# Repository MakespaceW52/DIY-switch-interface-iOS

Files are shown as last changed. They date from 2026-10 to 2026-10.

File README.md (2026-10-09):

# DIY BLE Switch Interface Module

> **A DIY Bluetooth accessibility switch interface for people with motor impairments — inspired by commercial devices like the AbleNet Blue2.**
---

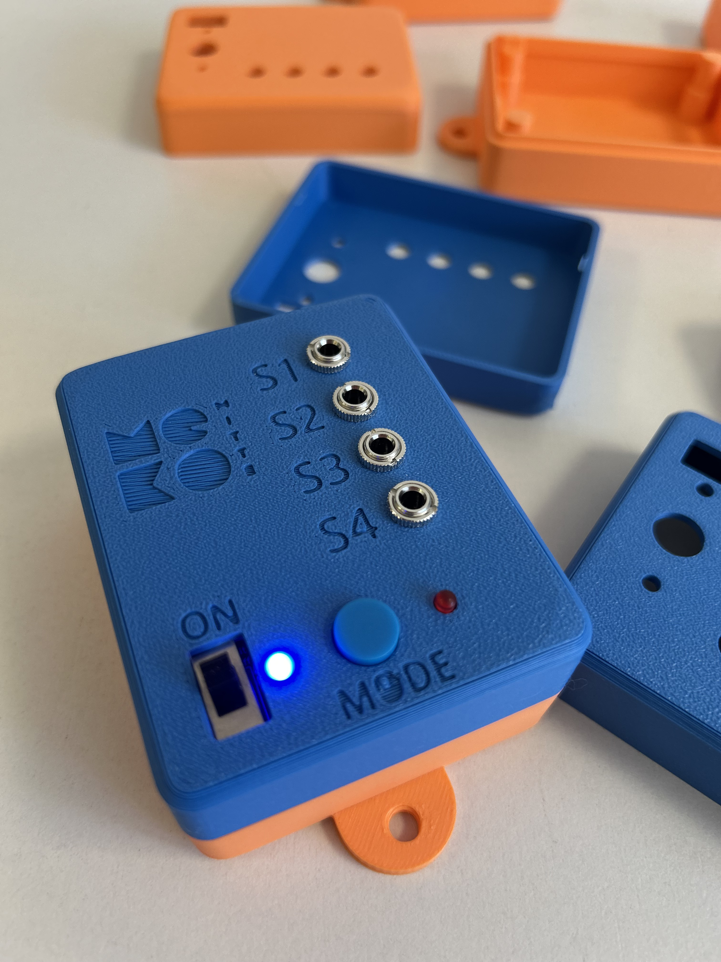
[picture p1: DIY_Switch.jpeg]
Ein Schalter Interface mit Klinkenbuchsen in einem selbstgedruckten Gehäuse.
\
Photo: © Meko Mitte

Bei Fragen / for questions contact: makespace@tjfbg.de

## English

### What is this?

The DIY BLE Switch Interface Module is an open-source Bluetooth HID adapter that connects up to **4 external switches** (via 3.5mm mono jack sockets) to iOS devices via Bluetooth Low Energy. A mode button cycles through configurable action profiles. Two LEDs indicate the current mode and Bluetooth connection status.

This project was developed at **Meko Mitte**, in their public makerspace for children and young people in Berlin, as an affordable and adaptable alternative to commercial assistive technology devices.

### Use Cases

- **Switch Control (iOS)** — Navigate the operating system's built-in accessibility features using one or more external switches (e.g. sip-and-puff, head switch, hand switch)
- **Media Control** — Play/pause, next/previous track, home button — for people who cannot easily reach device controls
- **Custom Input** — Any key combination or consumer HID command, freely configurable per switch and per mode
- **AAC Support** — Can be used as a switch interface for augmentative and alternative communication (AAC) apps

### Components

| Component | Description |
|---|---|
| **Adafruit Feather nRF52832 Bluefruit LE** | Main microcontroller board with integrated BLE (nRF52832 chip). Runs the Arduino sketch and handles all Bluetooth HID communication. |
| **3.5mm Mono Jack Sockets (×4)** | Input connectors for external switches. Tip → GPIO pin, Sleeve → GND. Compatible with most standard assistive technology switches. |
| **Push Button (momentary, NO)** | Mode selection button. Cycles through the configured action profiles. Each mode change is confirmed by the red LED blinking. |
| **LED red (3mm diffuse)** | Mode indicator. Blinks X times to confirm the active mode (1× = Mode 0, 2× = Mode 1, 3× = Mode 2). |
| **LED blue (3mm diffuse)** | Bluetooth status indicator. Slow blink = searching for device. Steady on = connected. Brief off = command sent. |
| **Resistor 330Ω** | Current limiting resistor for the red LED. |
| **Resistor 100Ω** | Current limiting resistor for the blue LED (higher forward voltage). |
| **Toggle Switch SPDT (2MS1)** | Power switch. Connected to the EN pin of the Feather to disable the 3.3V regulator when off. Protects the LiPo battery from deep discharge. |
| **LiPo Battery** | Powers the module wirelessly. The Feather's onboard charging circuit charges the battery via USB. |
| **Custom PCB** | KiCad-designed carrier board for all components. Gerber files included. |
| **3D Printed Enclosure** | Printable housing (FDM, PETG recommended). Source files and STLs included. |

### Modes (configurable in code)

| Mode | S1 | S2 | S3 | S4 |
|---|---|---|---|---|
| 0 – Switch Control | Space | Enter | Tab | Escape |
| 1 – Media | Play/Pause | Next | Previous | Home |
| 2 – Custom | 'a' | 'b' | disabled | disabled |

### Pin Assignment

| Function | Pin | Note |
|---|---|---|
| Switch 1 | 7 | INPUT_PULLUP |
| Switch 2 | 11 | INPUT_PULLUP |
| Switch 3 | 15 | INPUT_PULLUP |
| Switch 4 | 16 | INPUT_PULLUP |
| Mode Button | A5 (P0.29) | INPUT_PULLUP |
| LED red | A0 (P0.26) | via 330Ω |
| LED blue | A1 (P0.27) | via 100Ω |
| Power Switch | EN pin | SPDT to GND |

### Build Your Own

1. **Order the PCB** — Upload the Gerber files from `/pcb/` to a PCB manufacturer (e.g. JLCPCB, PCBWay, Aisler)
2. **Print the enclosure** — Print the files from `/case/` in PLA. Layer height 0.2mm, 3–4 wall lines.
3. **Solder the components** — Follow the schematic in kicad files in `/pcb/`
4. **Flash the firmware** — Open `_DIY_iOS_Blueetooth_Switch_v5.ino` in Arduino IDE, select board `Adafruit Bluefruit nRF52832 Feather`, upload
5. **Pair via Bluetooth** — The device appears as `DIY_Switch`. Enable Switch Control or accessibility features on your device and connect.

> **Note on power:** The EN-pin switch cuts the 3.3V regulator. The LiPo charging circuit remains active. Always use a protected LiPo battery.

### License

Open source — built with ❤️ at Meko Mitte for and with the community.

---

## Deutsch

### Was ist das?

Das DIY BLE Switch Interface Module ist ein Open-Source Bluetooth-HID-Adapter, der bis zu **4 externe Schalter** (über 3,5mm Mono-Klinkenbuchsen) per Bluetooth Low Energy mit iOS verbindet. Ein Modus-Button schaltet zwischen konfigurierbaren Aktionsprofilen um. Zwei LEDs zeigen den aktiven Modus und den Bluetooth-Verbindungsstatus an.

Das Projekt entstand im **Meko Mitte**, in deren öffentlichem Makespace für Kinder und Jugendliche in Berlin, als erschwingliche und anpassbare Alternative zu kommerziellen Hilfsmittelgeräten.

### Anwendungsszenarien

- **Switch Control (iOS)** — Steuerung der eingebauten Bedienungshilfen des Betriebssystems mit einem oder mehreren externen Schaltern (z.B. Sip-and-Puff, Kopfschalter, Handschalter)
- **Mediensteuerung** — Play/Pause, Nächster/Vorheriger Titel, Home-Taste — für Menschen, die Gerätebedienelemente schwer erreichen können
- **Benutzerdefinierte Eingabe** — Beliebige Tastenkombinationen oder Consumer-HID-Befehle, frei konfigurierbar pro Schalter und pro Modus
- **UK / Unterstützte Kommunikation** — Einsatz als Schalterinterface für UK-Apps (Unterstützte und Alternative Kommunikation)

### Komponenten

| Komponente | Beschreibung |
|---|---|
| **Adafruit Feather nRF52832 Bluefruit LE** | Haupt-Mikrocontroller-Board mit integriertem BLE (nRF52832-Chip). Führt den Arduino-Sketch aus und übernimmt die gesamte Bluetooth-HID-Kommunikation. |
| **3,5mm Mono-Klinkenbuchsen (×4)** | Eingänge für externe Schalter. Tip → GPIO-Pin, Sleeve → GND. Kompatibel mit den meisten Standard-Hilfsmittelschaltern. |
| **Drucktaster (momentan, NO)** | Modus-Wahltaster. Schaltet durch die konfigurierten Aktionsprofile. Jeder Moduswechsel wird durch Blinken der roten LED bestätigt. |
| **LED rot (3mm diffus)** | Modus-Anzeige. Blinkt X-mal zur Bestätigung des aktiven Modus (1× = Modus 0, 2× = Modus 1, 3× = Modus 2). |
| **LED blau (3mm diffus)** | Bluetooth-Statusanzeige. Langsames Blinken = Suche nach Gerät. Dauerhaft an = verbunden. Kurz aus = Befehl gesendet. |
| **Widerstand 330Ω** | Vorwiderstand für die rote LED. |
| **Widerstand 100Ω** | Vorwiderstand für die blaue LED (höhere Flussspannung). |
| **Kippschalter SPDT (2MS1)** | Ein-/Ausschalter. Am EN-Pin des Feather angeschlossen, um den 3,3V-Regler abzuschalten. Schützt den LiPo-Akku vor Tiefentladung. |
| **LiPo-Akku** | Versorgt das Modul kabellos mit Strom. Der integrierte Ladekreis des Feather lädt den Akku per USB. |
| **Eigene Platine (PCB)** | In KiCad entworfene Trägerplatine für alle Komponenten. Gerber-Dateien inklusive. |
| **3D-gedrucktes Gehäuse** | Druckbares Gehäuse (FDM, PETG empfohlen). Quelldateien und STLs inklusive. |

### Modi (im Code konfigurierbar)

| Modus | S1 | S2 | S3 | S4 |
|---|---|---|---|---|
| 0 – Switch Control | Leertaste | Enter | Tab | Escape |
| 1 – Medien | Play/Pause | Weiter | Zurück | Home |
| 2 – Benutzerdefiniert | 'a' | 'b' | deaktiviert | deaktiviert |

### Pinbelegung

| Funktion | Pin | Hinweis |
|---|---|---|
| Schalter 1 | 7 | INPUT_PULLUP |
| Schalter 2 | 11 | INPUT_PULLUP |
| Schalter 3 | 15 | INPUT_PULLUP |
| Schalter 4 | 16 | INPUT_PULLUP |
| Modus-Button | A5 (P0.29) | INPUT_PULLUP |
| LED rot | A0 (P0.26) | über 330Ω |
| LED blau | A1 (P0.27) | über 100Ω |
| Ein-/Ausschalter | EN-Pin | SPDT nach GND |

### Selbstbau

1. **Platine bestellen** — Gerber-Dateien aus `/pcb/` bei einem PCB-Hersteller hochladen (z.B. JLCPCB, PCBWay, Aisler)
2. **Gehäuse drucken** — Dateien aus `/case/` in PLA drucken.
3. **Komponenten löten** — Schaltplan in kicad datei `/pcb/` als Vorlage nutzen
4. **Firmware flashen** — `_DIY_iOS_Blueetooth_Switch_v5.ino` in der Arduino IDE öffnen, Board `Adafruit Bluefruit nRF52832 Feather` auswählen, hochladen
5. **Bluetooth koppeln** — Das Gerät erscheint als `DIY_Switch`. Switch Control oder Bedienungshilfen am Zielgerät aktivieren und verbinden.

> **Hinweis zum Akku:** Der EN-Pin-Schalter trennt den 3,3V-Regler. Der LiPo-Ladekreis bleibt aktiv. Bitte immer geschützte LiPo-Akkus verwenden.

### Lizenz

Open Source — mit ❤️ bei Meko Mitte für und mit der Community entstanden.

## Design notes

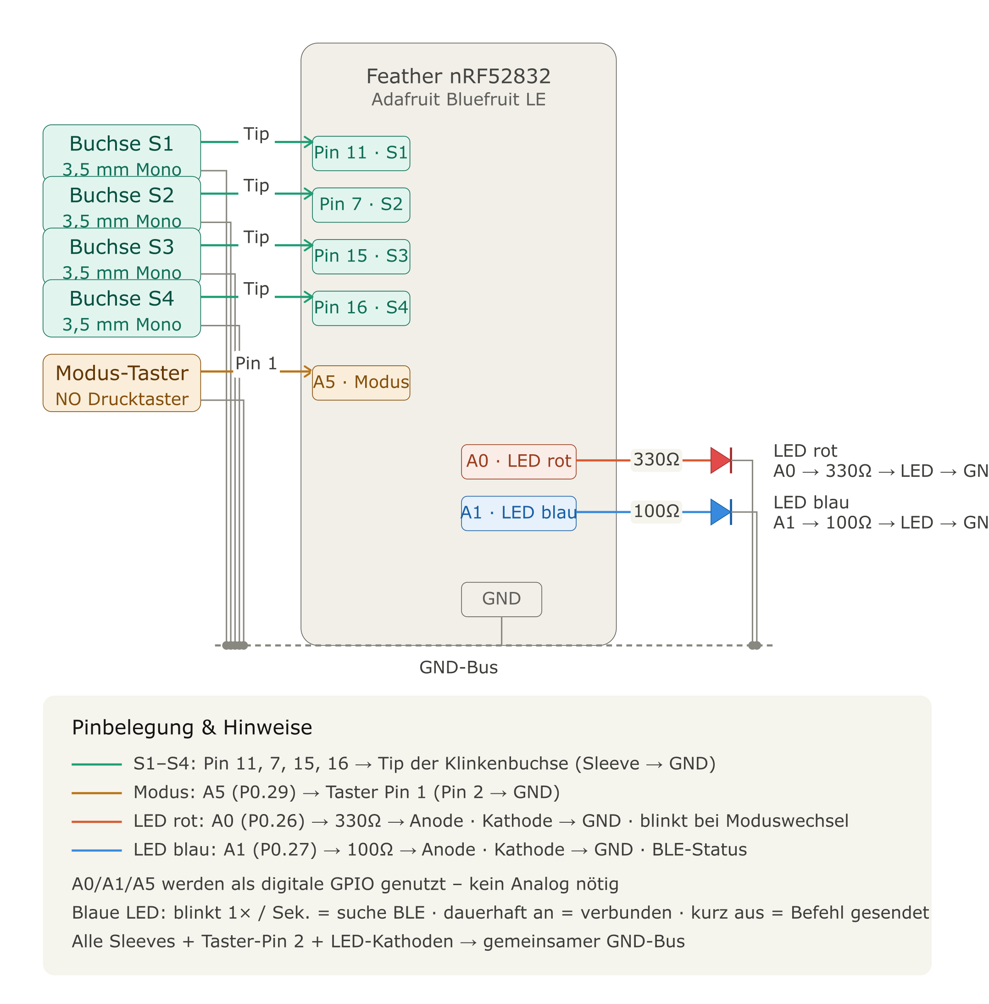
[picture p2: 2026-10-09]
schaltplan_v5.png

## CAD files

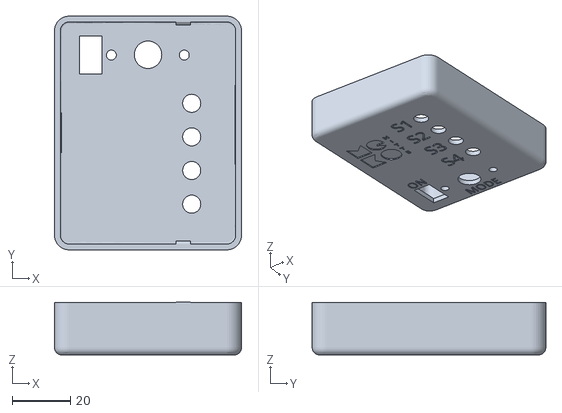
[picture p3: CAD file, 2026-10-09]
case/DIY-Switch_top_v5.stl
64.0 x 80.0 x 18.1

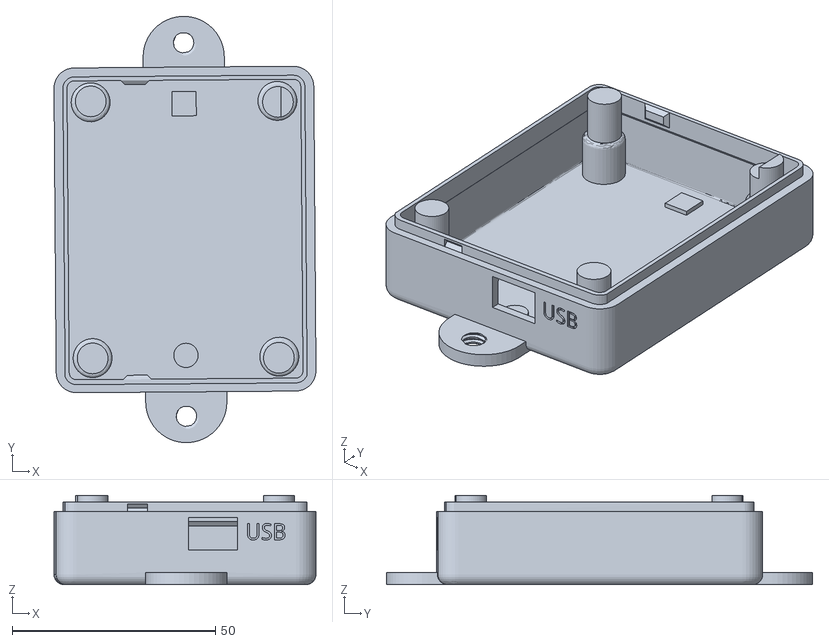
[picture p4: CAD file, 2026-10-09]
case/DIY-Switch_bottom_v4.stl
64.5 x 105.0 x 22.0

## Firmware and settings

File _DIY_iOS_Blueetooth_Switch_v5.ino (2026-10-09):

/*********************************************************************
 * DIY BLE Switch Module – nRF52 (Adafruit Feather 52 / Bluefruit)
 *
 * 4 externe Schalter (Mono-Klinkenbuchsen, INPUT_PULLUP)
 * 1 Modus-Button zum Durchschalten der Modi
 * LED rot  – blinkt X-mal bei Moduswechsel
 * LED blau – zeigt BLE-Verbindungsstatus
 *
 * ---------------------------------------------------------------
 * KONFIGURATION: Nur diesen Abschnitt anpassen
 * ---------------------------------------------------------------
 *********************************************************************/
#include <bluefruit.h>

// --- Pin-Definitionen -------------------------------------------
const int PIN_S1        = 7;   // Schalter 1 (Klinkenbuchse)
const int PIN_S2        = 11;   // Schalter 2 (Klinkenbuchse)
const int PIN_S3        = 15;   // Schalter 3 (Klinkenbuchse)
const int PIN_S4        = 16;   // Schalter 4 (Klinkenbuchse)
const int PIN_MODE_BTN  = PIN_A5;   // Modus-Wechsel-Button  (A5 = P0.29)
const int PIN_LED_RED   = PIN_A0;   // Externe rote LED  – Modus-Anzeige (A0 = P0.26)
const int PIN_LED_BLUE  = PIN_A1;   // Externe blaue LED – BLE-Status    (A1 = P0.27)

// --- BLE-Gerätename ---------------------------------------------
const char* DEVICE_NAME = "DIY_Switch";

// --- Anzahl Modi ------------------------------------------------
const int NUM_MODES = 3;

// --- Aktionstypen -----------------------------------------------
#define TYPE_NONE     0   // Schalter deaktiviert
#define TYPE_KEY      1   // Tastatur-Zeichen (HID keyPress)
#define TYPE_CONSUMER 2   // Consumer-Control (z.B. Play/Pause)

// --- HID Consumer-Codes -----------------------------------------
#define CONTROL_PLAY_PAUSE      0x00CD
#define CONTROL_SCAN_NEXT       0x00B5
#define CONTROL_SCAN_PREVIOUS   0x00B6
#define CONTROL_MUTE            0x00E2
#define AC_FORWARD              0x0225
#define AC_BACK                 0x0224
#define CONSUMER_BROWSER_HOME   0x0223

// --- Modus-Tabelle ----------------------------------------------
// Aufbau pro Eintrag: { TYPE, Wert }
// TYPE_KEY      -> Wert = ASCII-Zeichen (z.B. ' ', '\n', '\t', 27=Esc)
// TYPE_CONSUMER -> Wert = HID Consumer-Code (z.B. CONTROL_PLAY_PAUSE)
// TYPE_NONE     -> Wert wird ignoriert

struct Action {
  uint8_t  type;
  uint16_t value;
};

// [Modus][Schalter S1..S4]
const Action modeConfig[NUM_MODES][4] = {
  // Modus 0: Switch Control (Bedienungshilfen iOS/Android)
  {
    { TYPE_KEY,      ' '   },   // S1 – Leertaste  (Select / Aktivieren)
    { TYPE_KEY,      '\n'  },   // S2 – Enter
    { TYPE_KEY,      '\t'  },   // S3 – Tab        (Vorwärts navigieren)
    { TYPE_KEY,      27    },   // S4 – Escape     (Zurück / Abbrechen)
  },
  // Modus 1: Mediensteuerung
  {
    { TYPE_CONSUMER, CONTROL_PLAY_PAUSE    },   // S1 – Play/Pause
    { TYPE_CONSUMER, CONTROL_SCAN_NEXT     },   // S2 – Nächster Titel
    { TYPE_CONSUMER, CONTROL_SCAN_PREVIOUS },   // S3 – Vorheriger Titel
    { TYPE_CONSUMER, CONSUMER_BROWSER_HOME },   // S4 – Home
  },
  // Modus 2: Benutzerdefiniert – hier frei belegen
  {
    { TYPE_KEY,      'a'   },   // S1
    { TYPE_KEY,      'b'   },   // S2
    { TYPE_NONE,     0     },   // S3 – deaktiviert
    { TYPE_NONE,     0     },   // S4 – deaktiviert
  },
};

// ---------------------------------------------------------------
// Ab hier: Laufzeit-Logik – normalerweise nicht anfassen
// ---------------------------------------------------------------

BLEDis          bledis;
BLEHidAdafruit  blehid;

// Pin-Array für die 4 Schalter
const int switchPins[4] = { PIN_S1, PIN_S2, PIN_S3, PIN_S4 };

// Debounce-Status
bool prevSwitchState[4] = { HIGH, HIGH, HIGH, HIGH };
bool prevModeBtnState   = HIGH;

// Aktiver Modus
int currentMode = 0;

// BLE-Verbindungsstatus
bool bleConnected = false;

// Timing für blaues BLE-Blinken (non-blocking)
unsigned long lastBlueToggle = 0;
bool          blueState      = false;

// ---------------------------------------------------------------
// BLE Callbacks
// ---------------------------------------------------------------
void connectCallback(uint16_t conn_hdl) {
  (void) conn_hdl;
  bleConnected = true;
  digitalWrite(PIN_LED_BLUE, HIGH);   // Dauerhaft an = verbunden
  Serial.println("BLE verbunden");
}

void disconnectCallback(uint16_t conn_hdl, uint8_t reason) {
  (void) conn_hdl;
  (void) reason;
  bleConnected = false;
  digitalWrite(PIN_LED_BLUE, LOW);
  Serial.println("BLE getrennt");
}

// ---------------------------------------------------------------
// Setup
// ---------------------------------------------------------------
void setup() {
  for (int i = 0; i < 4; i++) {
    pinMode(switchPins[i], INPUT_PULLUP);
  }
  pinMode(PIN_MODE_BTN,  INPUT_PULLUP);
  pinMode(PIN_LED_RED,   OUTPUT);
  pinMode(PIN_LED_BLUE,  OUTPUT);
  digitalWrite(PIN_LED_RED,  LOW);
  digitalWrite(PIN_LED_BLUE, LOW);

  Serial.begin(115200);
  unsigned long t = millis();
  while (!Serial && millis() - t < 2000) delay(10);

  Serial.println("DIY BLE Switch Module – Start");
  Serial.print("Modi: ");
  Serial.println(NUM_MODES);

  Bluefruit.begin();
  Bluefruit.setTxPower(4);
  Bluefruit.setName(DEVICE_NAME);

  // BLE Callbacks registrieren
  Bluefruit.Periph.setConnectCallback(connectCallback);
  Bluefruit.Periph.setDisconnectCallback(disconnectCallback);

  bledis.setManufacturer("Meko Mitte");
  bledis.setModel("BLE Switch v2");
  bledis.begin();

  blehid.begin();

  startAdv();

  // Startmodus anzeigen (rote LED)
  blinkMode(currentMode + 1);
}

// ---------------------------------------------------------------
// BLE Advertising
// ---------------------------------------------------------------
void startAdv() {
  Bluefruit.Advertising.addFlags(BLE_GAP_ADV_FLAGS_LE_ONLY_GENERAL_DISC_MODE);
  Bluefruit.Advertising.addTxPower();
  Bluefruit.Advertising.addAppearance(BLE_APPEARANCE_HID_KEYBOARD);
  Bluefruit.Advertising.addService(blehid);
  Bluefruit.Advertising.addName();
  Bluefruit.Advertising.restartOnDisconnect(true);
  Bluefruit.Advertising.setInterval(32, 244);
  Bluefruit.Advertising.setFastTimeout(30);
  Bluefruit.Advertising.start(0);
}

// ---------------------------------------------------------------
// Rote LED blinkt n-mal (Modus-Anzeige)
// ---------------------------------------------------------------
void blinkMode(int times) {
  for (int i = 0; i < times; i++) {
    digitalWrite(PIN_LED_RED, HIGH);
    delay(120);
    digitalWrite(PIN_LED_RED, LOW);
    if (i < times - 1) delay(120);
  }
}

// ---------------------------------------------------------------
// Blaue LED: langsames Blinken wenn nicht verbunden (non-blocking)
// ---------------------------------------------------------------
void updateBlueLED() {
  if (bleConnected) return;   // Verbunden → LED wird im Callback gesteuert
  unsigned long now = millis();
  if (now - lastBlueToggle >= 1000) {
    blueState = !blueState;
    digitalWrite(PIN_LED_BLUE, blueState ? HIGH : LOW);
    lastBlueToggle = now;
  }
}

// ---------------------------------------------------------------
// Consumer-Taste senden (z.B. Play/Pause)
// ---------------------------------------------------------------
void sendConsumer(uint16_t command) {
  for (uint16_t conn_hdl = 0; conn_hdl < BLE_MAX_CONNECTION; conn_hdl++) {
    BLEConnection* connection = Bluefruit.Connection(conn_hdl);
    if (connection && connection->connected() && connection->bonded()) {
      blehid.consumerKeyPress(conn_hdl, command);
      delay(10);
      blehid.consumerKeyRelease(conn_hdl);
    }
  }
  // Kurzes Feedback: blaue LED blinkt kurz ab
  if (bleConnected) {
    digitalWrite(PIN_LED_BLUE, LOW);
    delay(50);
    digitalWrite(PIN_LED_BLUE, HIGH);
  }
  delay(50);
}

// ---------------------------------------------------------------
// Tastatur-Taste senden (z.B. Leertaste, Enter)
// ---------------------------------------------------------------
void sendKey(char key) {
  blehid.keyPress(key);
  delay(10);
  blehid.keyRelease();
  // Kurzes Feedback: blaue LED blinkt kurz ab
  if (bleConnected) {
    digitalWrite(PIN_LED_BLUE, LOW);
    delay(50);
    digitalWrite(PIN_LED_BLUE, HIGH);
  }
  delay(50);
}

// ---------------------------------------------------------------
// Aktion ausführen (liest aus modeConfig)
// ---------------------------------------------------------------
void executeAction(int switchIndex) {
  Action a = modeConfig[currentMode][switchIndex];
  switch (a.type) {
    case TYPE_KEY:
      sendKey((char)a.value);
      Serial.print("KEY S");
      break;
    case TYPE_CONSUMER:
      sendConsumer(a.value);
      Serial.print("CONSUMER S");
      break;
    case TYPE_NONE:
    default:
      return;
  }
  Serial.print(switchIndex + 1);
  Serial.print(" Modus ");
  Serial.println(currentMode);
}

// ---------------------------------------------------------------
// Modus-Button verarbeiten (Flanken-Debounce)
// ---------------------------------------------------------------
void handleModeButton() {
  bool cur = digitalRead(PIN_MODE_BTN);
  if (cur == LOW && prevModeBtnState == HIGH) {
    currentMode = (currentMode + 1) % NUM_MODES;
    Serial.print("Modus gewechselt -> ");
    Serial.println(currentMode);
    delay(20);
    blinkMode(currentMode + 1);
  }
  prevModeBtnState = cur;
}

// ---------------------------------------------------------------
// Loop
// ---------------------------------------------------------------
void loop() {
  handleModeButton();
  updateBlueLED();

  for (int i = 0; i < 4; i++) {
    bool cur = digitalRead(switchPins[i]);
    if (cur == LOW && prevSwitchState[i] == HIGH) {
      executeAction(i);
    }
    prevSwitchState[i] = cur;
  }

  delay(10);
}
